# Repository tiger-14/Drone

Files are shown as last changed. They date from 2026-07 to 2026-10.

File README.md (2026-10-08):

# TSA Drone Project
A custom-built quadcopter drone with an integrated claw and live video feed, designed to remotely locate and retrieve caged and uncaged animals for TSA's 2026 Drone Challenge (Safari Rescue mission).





## 30+ Page Documentation Portfolio
The portfolio documents the complete build process of the drone with a photo log, a work log, engineered drawings, wired diagrams, and more

[Documentation Portfolio - Drone Challenge UAV.pdf](https://raw.githubusercontent.com/tiger-14/drone/main/Documentation%20Portfolio%20-%20Drone%20Challenge%20UAV.pdf)

## Features

- 3D-printed frame, base structure, and claw mechanism, designed in SolidWorks
- 4x brushless motors (RS2205 2300KV) with tri-blade propellers for lift and thrust
- SoloGood F722 flight controller stack running Betaflight firmware in Angle Mode for automatic self-leveling
- BetaFPV ELRS 2.4GHz receiver paired with a BetaFPV controller for piloting
- Raspberry Pi Zero WH running Raspberry Pi OS, controlling the claw servos and USB webcam independently of the flight stack
- 3x SG90 micro servos actuating a 3-pronged claw for picking up and releasing targets
- XT30/XT60 smoke stopper for short-circuit protection
- Dual 3S LiPo 11.1V 5000mAh batteries

## How it works

The pilot flies the drone using a BetaFPV controller, which sends inputs to the onboard ELRS receiver at up to 500Hz. Betaflight, running on the SoloGood F722 stack, reads these inputs alongside data from the onboard IMU (gyroscope + accelerometer) and calculates motor outputs at 4-8kHz to keep the drone stable. In Angle Mode, the drone self-levels whenever the sticks are centered, which keeps it steady during claw operations without needing constant manual correction.

A Raspberry Pi Zero WH, handles the claw and camera. It drives the 3 SG90 servos that open and close the claw, and streams a live feed from a USB webcam back to the pilot's laptop for target identification. Betaflight and the Pi operate independently: Betaflight handles flight, the Pi handles the mission payload.

## Bill of Materials

| Part | Description | Qty |
|---|---|---|
| Anycubic Kobra 2 | 3D printer | 1 |
| Sunlu PETG | Print filament | 4 |
| Drone Frame (3D-printed) | Upper + lower frame housing all components | 2 |
| XT30/XT60 FPV Smoke Stopper | Short-circuit protection | 1 |
| Raspberry Pi Zero WH | Claw + video control | 1 |
| OVONIC D15 Dual LiPo Charger | Battery charging | 1 |
| 3S LiPo 11.1V 5000mAh | Power | 2 |
| BetaFPV Controller | Piloting | 1 |
| BetaFPV ELRS (2.4GHz, 500Hz) | Radio link | 1 |
| SoloGood F722 Stack | Flight controller | 1 |
| Readytosky RS2205 2300KV Brushless Motor | Lift/thrust | 4 |
| 5.1" 3-Paddle Propellers | — | 12 |
| Webcam | Target ID / video feed | 1 |
| SG90 Micro Servos | Claw actuation | 3 |
| 5V Converter | Powers Pi + servos | 1 |
| Claw (3D-printed) | Pickup mechanism | 1 |

## Compliance

Built and flown in accordance with FAA Part 107 and Remote ID requirements, 400ft altitude ceiling, and Georgia state UAS regulations. Full regulatory breakdown in the documentation portfolio.

## Credits

Built by Benjamin Antony, Taran Vijayakumar, Nathaniel Ramnath, and Ivin George for South Forsyth High School's TSA chapter — Georgia TSA SLC 2026, Athens, GA.

3D model sources: claw arm, landing gear, propeller guard, Pi enclosure, servo/webcam mounts, and drone frame base are credited with links in the documentation portfolio's Resources section.

## License


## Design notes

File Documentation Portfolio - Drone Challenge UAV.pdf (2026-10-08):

## Drone Challenge (UAV) 2026 Safari Rescue - HS Drone UAV

Conference City and State:

Georgia TSA State Leadership Conference (SLC) 2026 Athens, Georgia

School/Chapter:

South Forsyth High School
Cumming, Georgia - 30041

Team Members:

Benjamin Anthony
Taran Vijayakumar
Nathaniel Ramnath
Ivin George

## Table of Contents

Section | Page
Photo Log | 3-12
Wiring Diagrams | 13
Programming Software Explanation | 14-16
Engineered Drawings | 17-19
Bill of Materials | 20-21
Drone Regulations | 22-23
Resources & Sources | 24
Worklog | 25-27
Student Copyright Checklist | 28-31

## Photo Log

Photo 1 - Designing the Drone Frame on SolidWorks

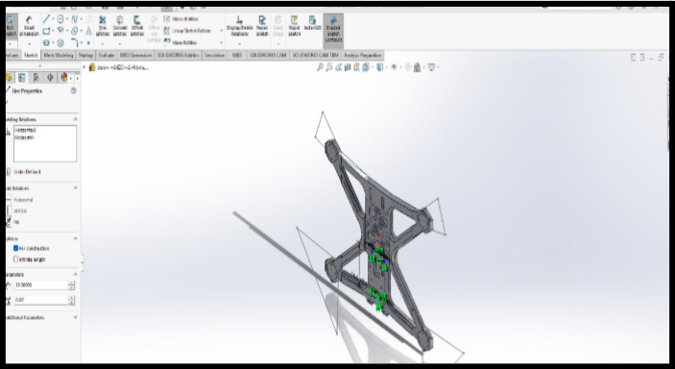
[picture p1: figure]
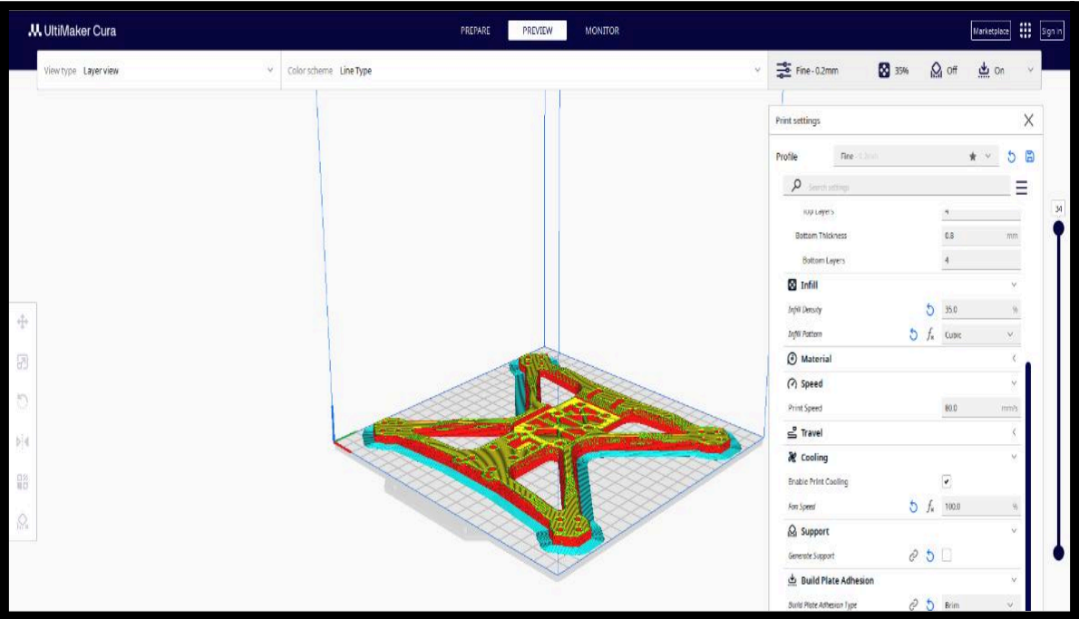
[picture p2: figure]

These images show the initial 3D modeling of the drone frame in SolidWorks. Designing the frame digitally allowed accurate planning before printing and ensured all components would fit properly.

Photo 2 - Attaching Motors to 3D-Printed Frame

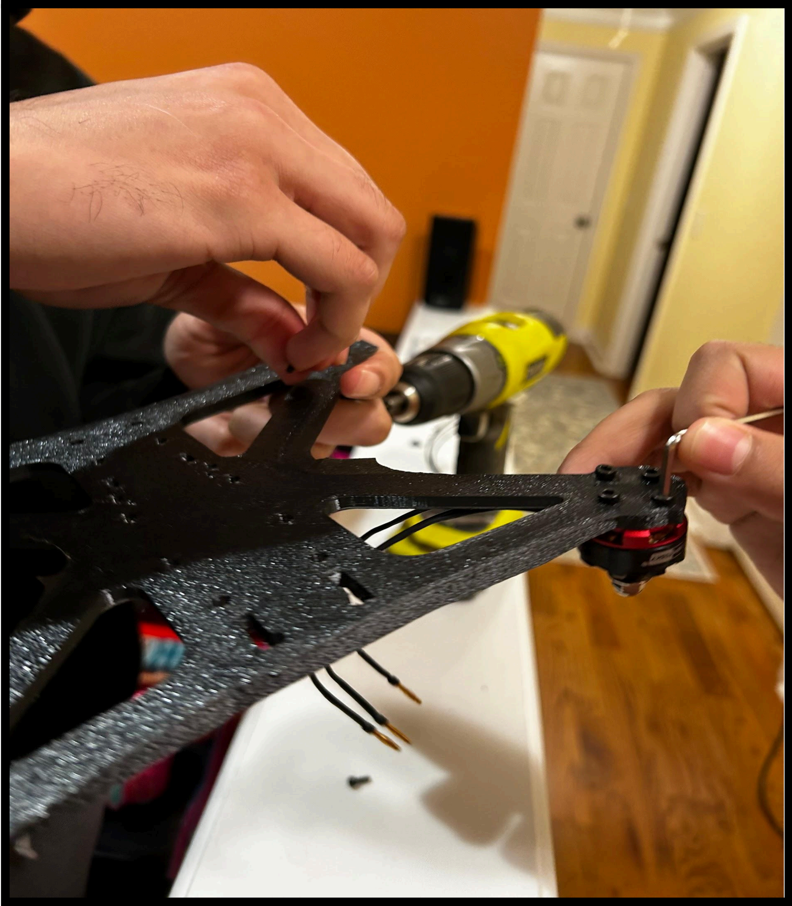
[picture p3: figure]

In this step, the motors were screwed onto the 3D-printed drone frame, ensuring each motor is securely mounted and ready for wiring.

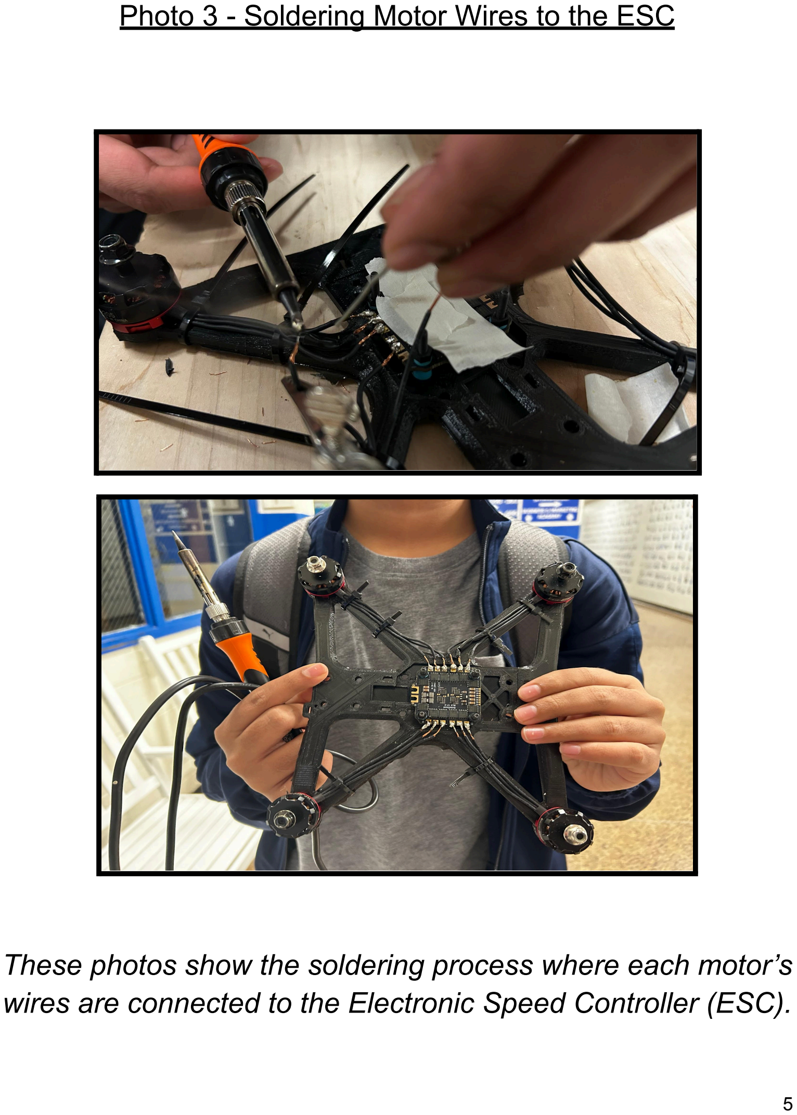
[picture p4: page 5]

Photo 3 - Soldering Motor Wires to the ESC

These photos show the soldering process where each motor’s wires are connected to the Electronic Speed Controller (ESC).

Photo 4 - Installing Flight Controller and ELRS

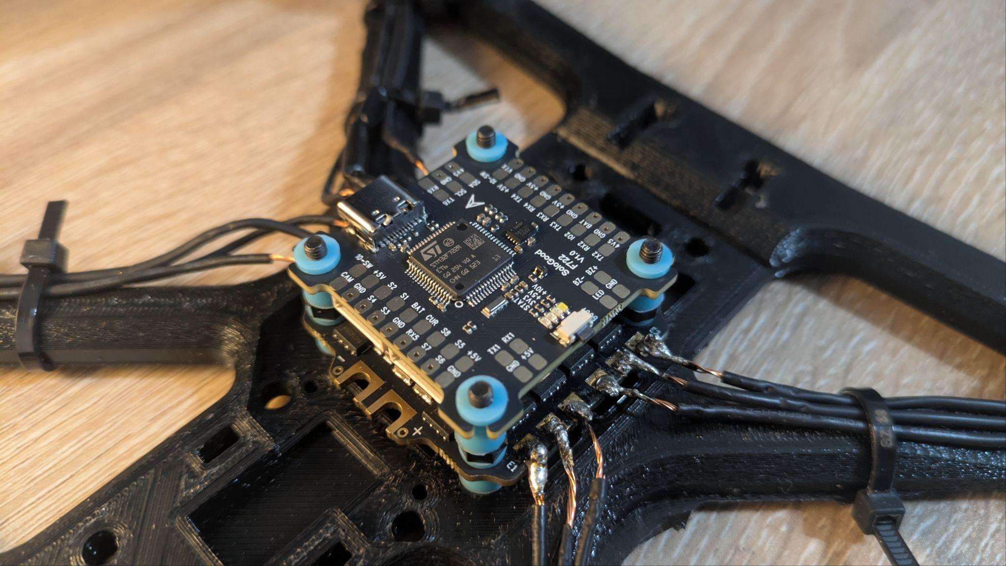
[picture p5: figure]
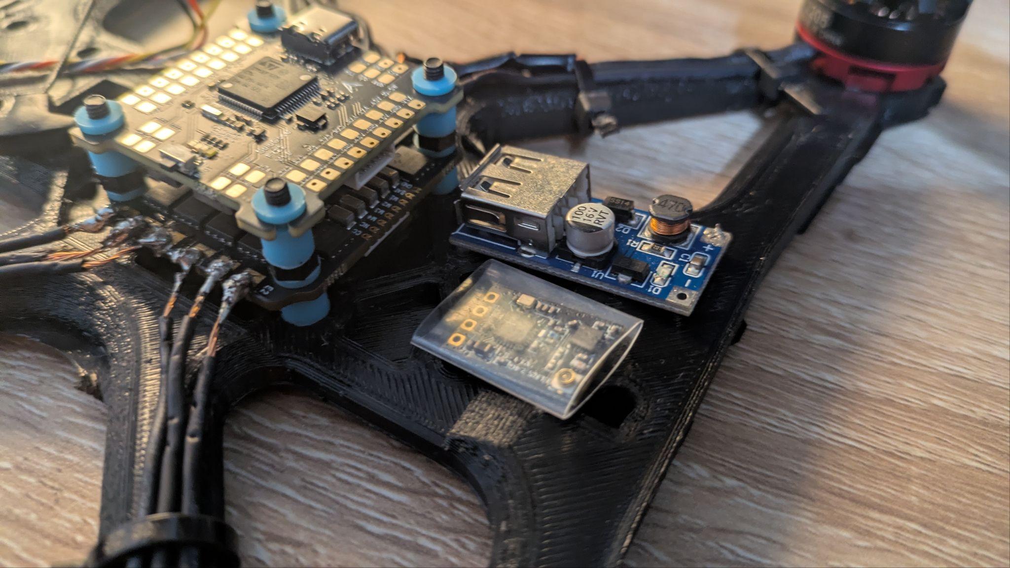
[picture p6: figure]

These photos show the installation of the flight controller and the ELRS receiver, completing the drone’s control and communication system.

Photo 5 - Installing Top Frame

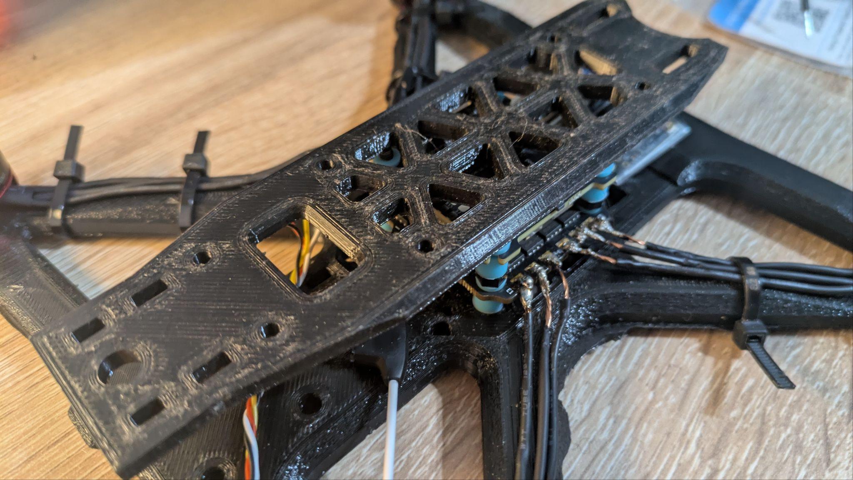
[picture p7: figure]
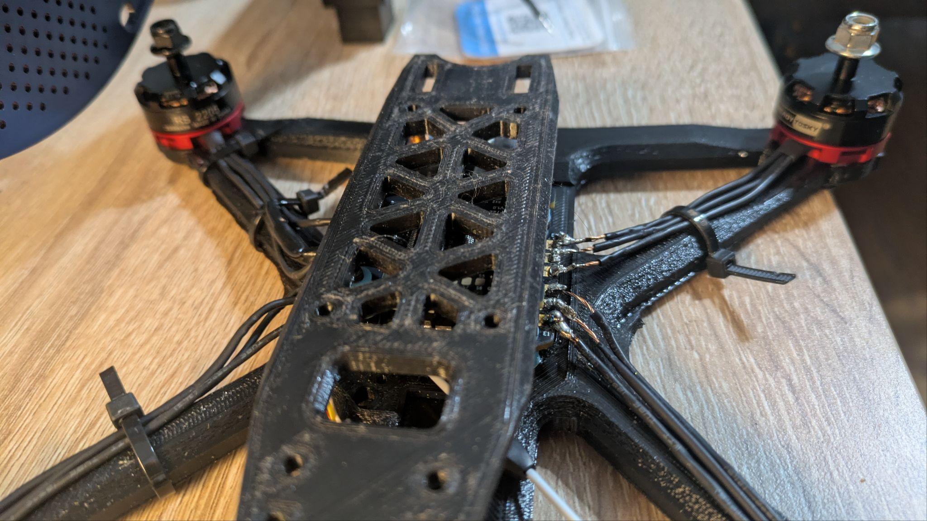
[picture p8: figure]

These photos show the installation of the 3D-printed top frame above the ESC, securing and protecting the components.

Photo 6 - Soldering battery wires to the ESC

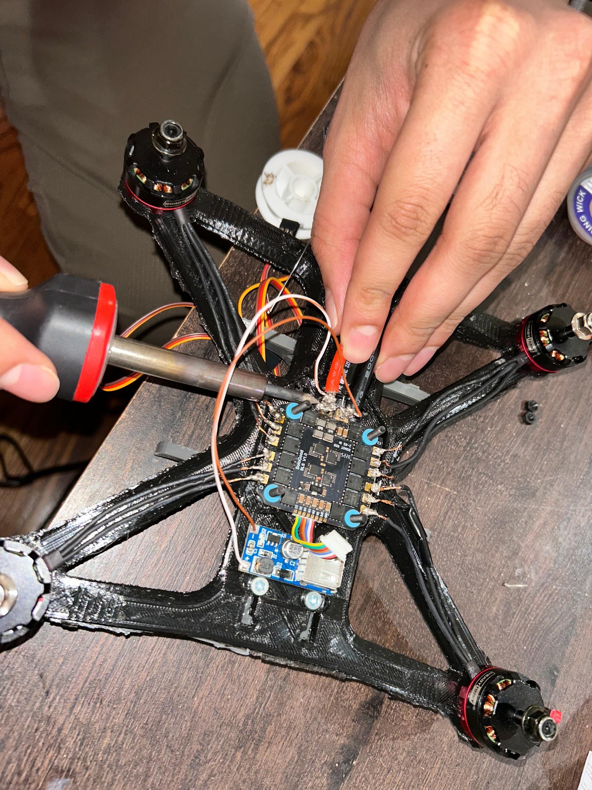
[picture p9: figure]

These photos show the soldering process where the drone’s battery power leads (positive red and negative black wires) are connected to the ESC power input pads, ensuring current delivery to all four motors.

Photo 7 - Connecting Ribbon Cable to the Flight Controller

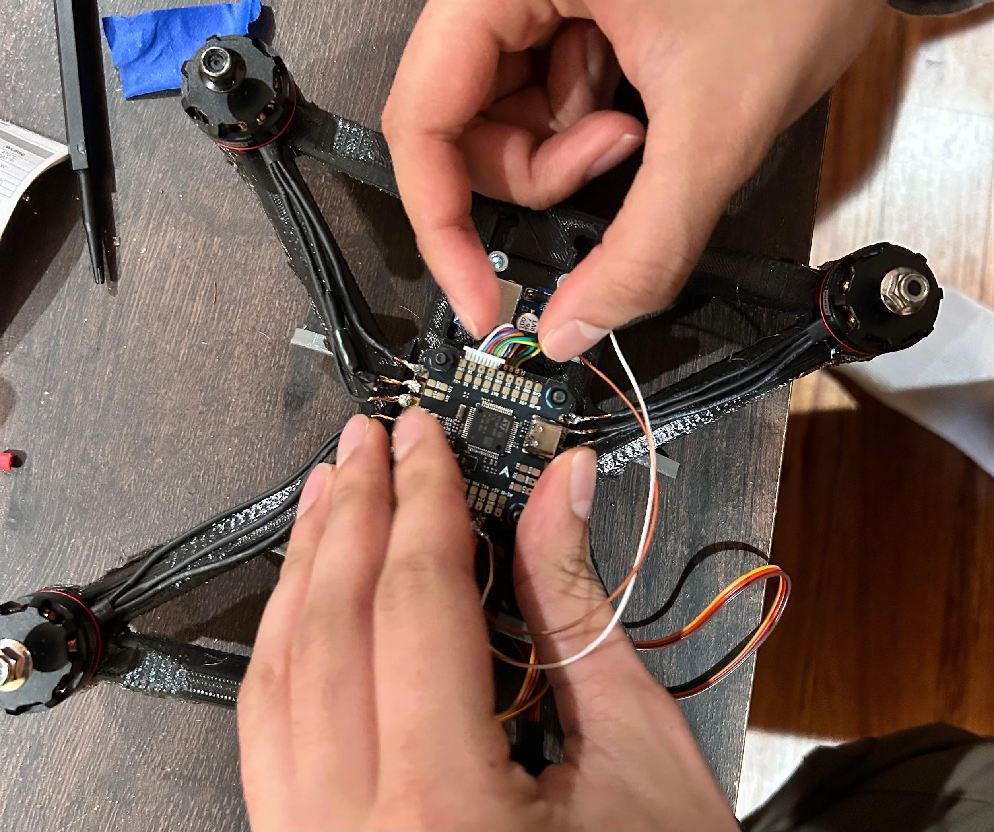
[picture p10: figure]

This photo shows the ribbon cable connection between the ESC and the flight controller for power and signal transmission.

Photo 8 - Connecting Ribbon Cable to the Flight Controller

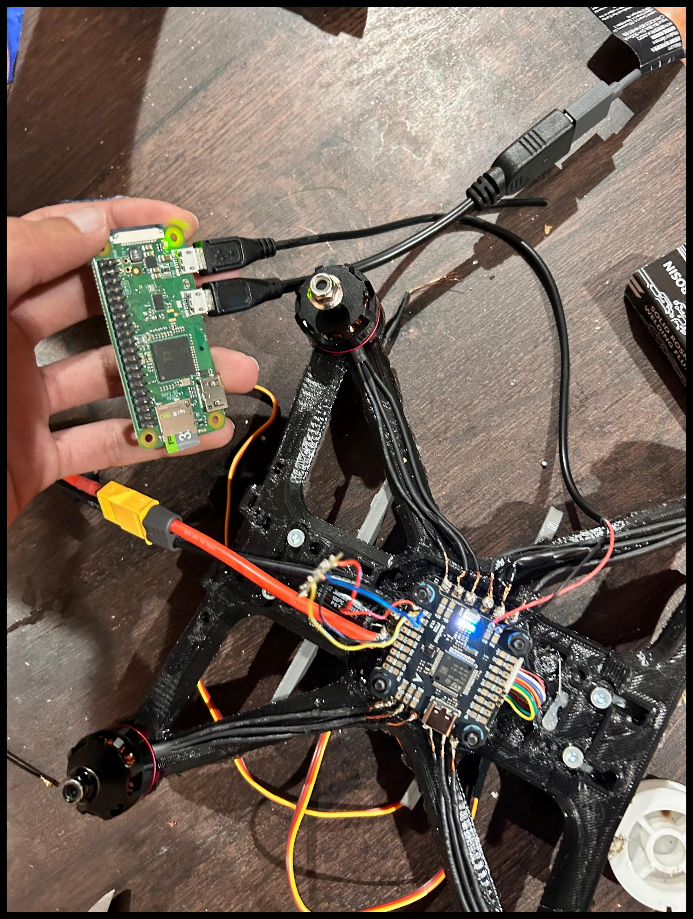
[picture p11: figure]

This photo shows the Raspberry Pi connected to the drone’s flight controller to control the claw and webcam.

Photo 9 - Raspberry Pi and Webcam Mounted

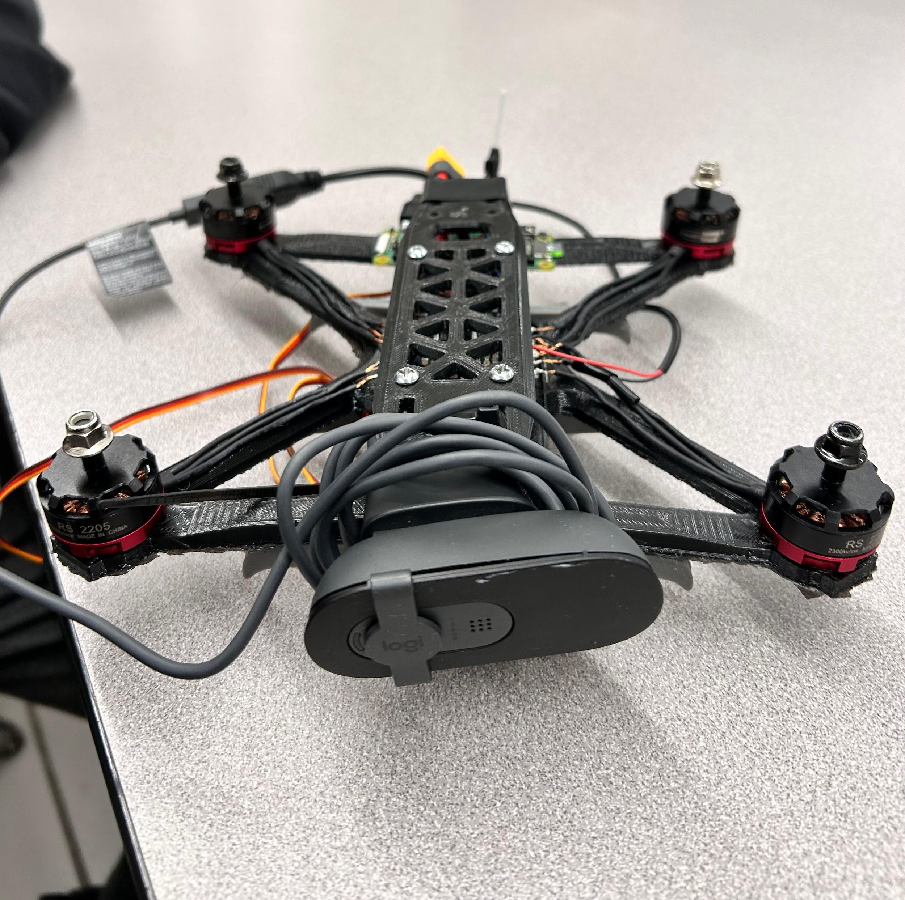
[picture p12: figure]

This photo shows the Raspberry Pi and webcam securely mounted on the drone frame.

Photo 10 - Drone connected to Betaflight configurator

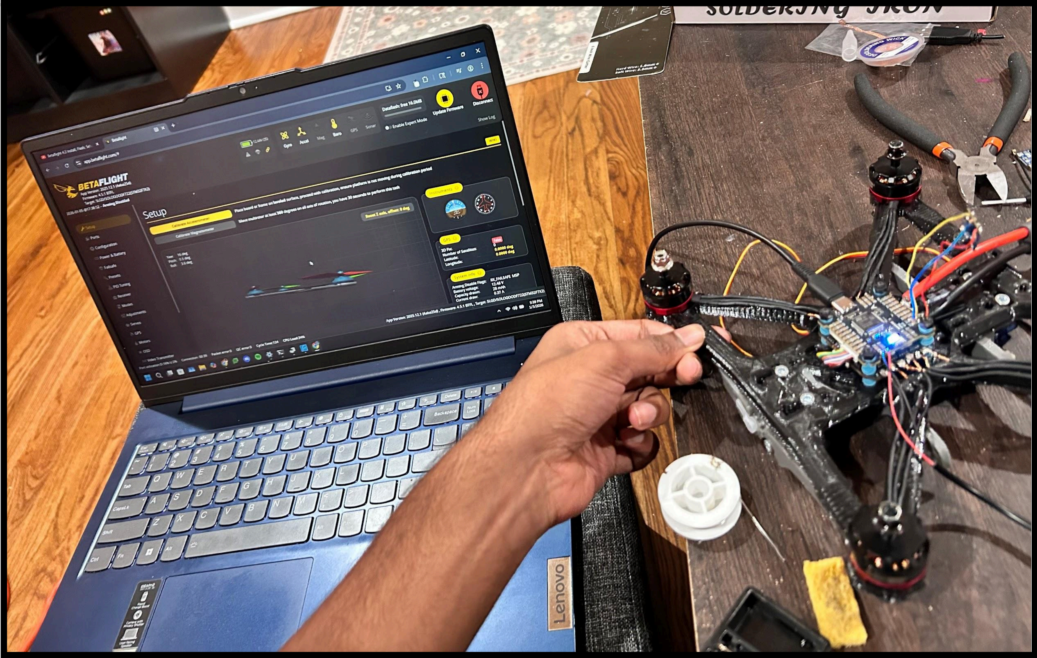
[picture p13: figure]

This photo shows the drone connected via USB to a laptop running Betaflight Configurator for flight control setup, receiver binding, controller and motor testing.

[Drone is currently under development. Photo log and other documentation will continue to be updated.]

## Wiring Diagram

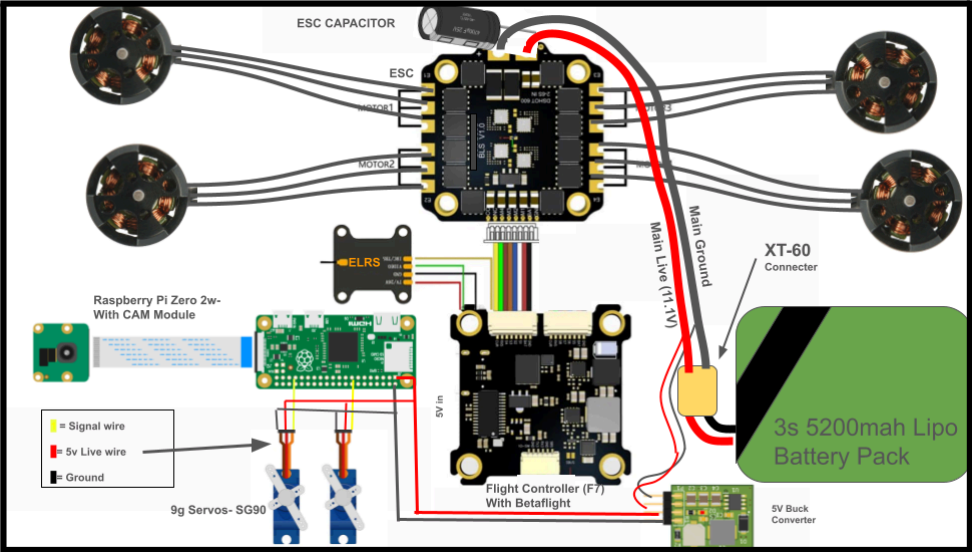
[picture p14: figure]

The information contained in this drawing is the sole property of Benjamin Antony, Taran Vijayakumar, Nathaniel Ramnath and Ivin George.

[Source of Flight Stack image: SoloGood FC Product Manual, used for illustrative purposes only]

## Programming Software

Betaflight is an open-source flight control firmware that runs on the drone’s flight controller microprocessor (in this build: STM32 F722 SoloGood stack) and acts as the central system coordinating all electronics. It continually processes pilot commands received via radio link (here using a BetaFPV ELRS 2.4 GHz receiver operating at 500Hz with the BetaFPV controller) while reading data from an Inertial Measurement Unit (IMU) containing a 3-axis gyroscope and 3-axis accelerometer.

For this Safari Rescue mission, we configured the drone to operate in Angle Mode, which provides automatic self-leveling for stability.Betaflight is good for our project because when the sticks are centered in Angle Mode, the outer loop commands zero tilt, causing the drone to actively self-level and maintain stable hover. This automatic stabilization is essential during our claw operations, as it eliminates the need for manual corrections and allows us to focus on collecting the target and claw positioning.

With Betaflight software, we will be able to tune our drone to our liking with many settings like PID, throttle response, and filters, which will allow the drone to fly optimally. The PID will be used for controlling how the vibrations from our brushless motors affect our drone in flight. This is extremely important to make sure our drone doesn't do anything that could cause harm to the components, which is exemplified by the fact that our frame is 3D printed.

Betaflight also allows us to configure the drone without manually making code for our specific motherboard, which will speed up the process of tuning and connecting the drone. Betaflight will also give us full control of everything connected to the motherboard, which includes servos, transmitter, and video broadcasting system.

Our flight control loop also operates at high speeds: the ICM42688P gyroscope can sample up to 8 kHz, with PID calculations typically running at 4-8 kHz depending on processor load and enabled features. This is combined with the ELRS (ExpressLRS) radio control protocol, which works with the controller’s pilot inputs sent to the ELRS receiver installed on the drone, with up to 500Hz update rate. Rapid input transmission from

ExpressLRS and high frequency sensor feedback from the gyroscope contribute to the drone’s extremely low latency.

We will be using Betaflight in conjunction with a Raspberry Pi Zero WH (which has its own power rail) to operate the claw system and transmit the video signal to our laptop. The Pi will be running Raspberry Pi OS, which is a custom version of Linux. This will connect to the signal wires for our servos and our USB webcam via the USB OTG port included in the microcomputer. The Betaflight software will also have control of our BetaFPV ELRS system, which connects the drone to the remote control system. This will allow us to tune our telemetry signal as well, and get the most performance out of our ELRS system for our specific use case.

Essentially, Betaflight is the flight control firmware that manages and allows all the major parts of the drone to work together.

## Engineered Drawings

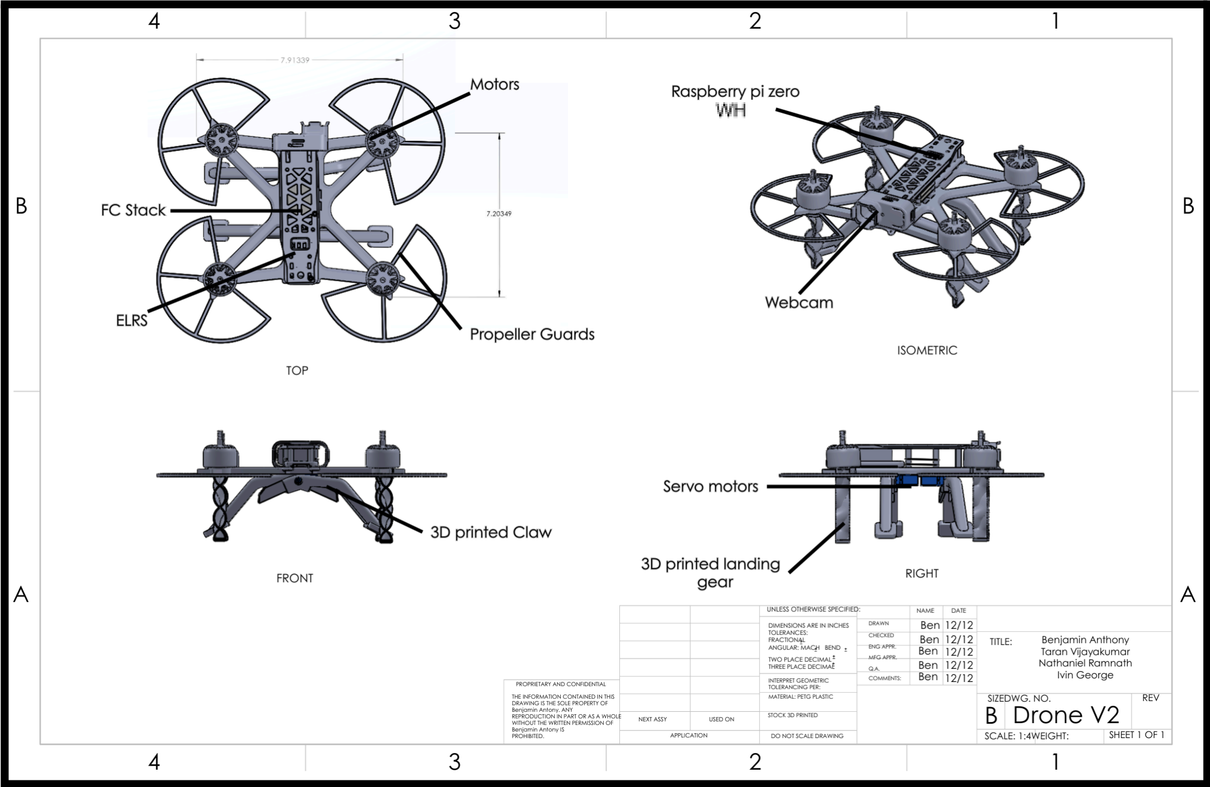
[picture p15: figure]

This engineered drawing shows the base frame, propeller and motor system, Raspberry Pi, claw, webcam, and all electronics. It shows the complete Safari Rescue drone configuration.

Base Frame

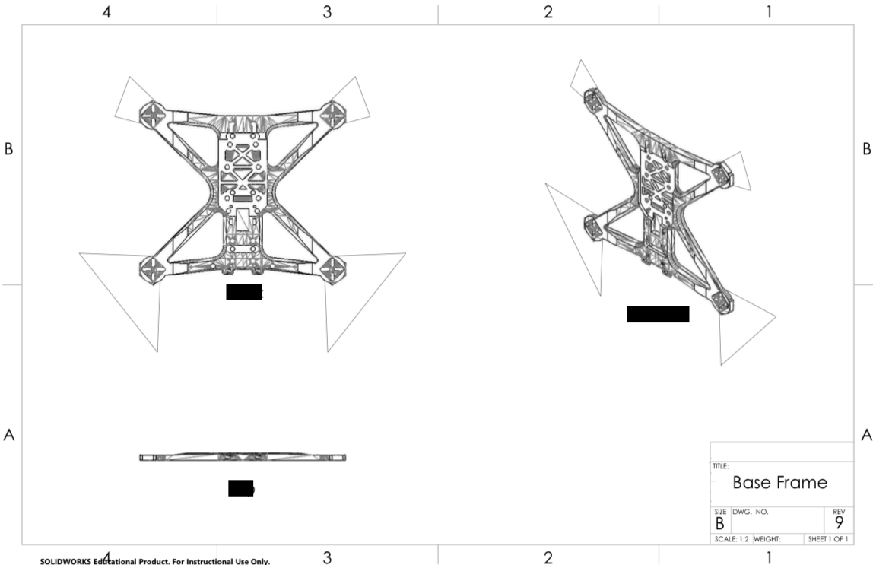
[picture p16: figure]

This engineered drawing shows the base frame with motor mounting holes and electronics mounting points. The design holds the motors, flight controller, ESC, and battery securely in place. It provides the main structure that connects all major components together for stable flight.

Gripper/Claw

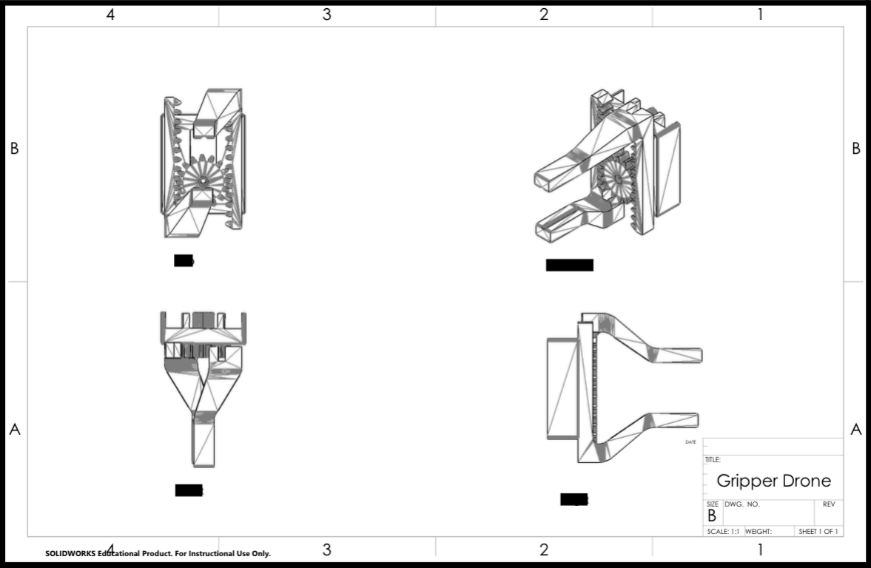
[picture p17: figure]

This engineered drawing shows the claw mechanism and grip design. It holds and releases the caged and uncaged animals for the safari rescue mission.

The information contained in these drawings are the sole property of Benjamin Antony, Taran Vijayakumar, Nathaniel Ramnath and Ivin George. Also reference the links in the Resources page.

## Bill of Materials

Parts | Description | Quantity
Anycubic Kobra 2 | 3D Printer | 1
Sunlu PETG | Filament for 3D printer | 4
Drone Frame | 3D-printed drone frame - It supports and protects all drone components, with the lower frame mounting the ESC and the upper frame supporting the flight controller, Raspberry Pi, and claw system. | 2
XT30/XT60 FPV Smoke Stopper (https://www.amazon.com/gp/aw/d/B0F8Q3GBMV/ref=ox_sc_act_image_1?smid=AX831X7Z04MWN&psc=1) | Short circuit protection - Protects stack and Raspberry Pi from catching on fire and protects | 1

electronic components from current surges.

Raspberry Pi Zero WH | For handling the video feed and servo motors | 1
OVONIC D15 Dual LiPo Battery Charger | Charges the battery | 1
3S LiPo 11.1V 5000mAh battery (https://www.amazon.com/gp/aw/d/B0D8SDTZ6P/ref=ox_sc_act_title_6?smid=A1KODDOPEPALCP&psc=1) | Powers the drone and associated systems | 2
Beta FPV controller (https://www.amazon.com/gp/aw/d/B09PV8C3D3/ref=ox_sc_act_title_3?smid=AHYBUG4B9GJPC&psc=1) | For controlling and piloting the drone | 1
Beta FPV ELRS (0.7 g, 2.4 GHz, 5 V, 500Hz) (https://www.amazon.com/gp/aw/d/B09B28HSVB/ref=ox_sc_act_title_4?smid=AHYBUG4B9GJPC&psc=1) | Sends signal from the drone to the controller | 1
SoloGood F722 Stack (https://www.amazon.com/gp/aw/d/B0CQJVGK14/ref=ox_sc_act_title_5?smid=A1JGQIWP459RKC&psc=1) | It acts like the motherboard of the drone, it determines motor speed and interprets signals | 1

Readytosky
RS2205 2300KV
Brushless Motor
CW/CCW 3-4S
RC Motors
| Brushless motor that spins propellers to generate lift and provide thrust for flight. | 4
| Creates lift to fly the drone | 12
Webcam | Provides a camera feed and target identification | 1
SG90 Micro Servos (from open-lab) | Powers the claw to pick up objects | 3
5V Converter (from open-lab) | 5V regulator to power Raspberry Pi and servos. | 1
Hand drill | Used for creating mounting holes to attach motors and other components to drone frame | 1
Claw | 3D printed and used to pick up objects | 1

5.1inch, 3-Paddle
Propellers (https://www.amazon.com/gp/aw/d/B0F632WFJQ/ref=ox_sc_act_title_7?smid=AX831X7Z04MWN&psc=1)

## Rules & Regulations

Federal Rules and Regulations:

In accordance with the Federal Aviation Administration (FAA) regulations, any unmanned aircraft weighing more than 250 grams must be registered with the FAA and must comply with RFID (Remote ID) requirements unless operated within a FAA-Recognized Identification Area (FRIA). Pilots must ensure that the aircraft’s Remote ID broadcast is functional prior to takeoff, as it transmits the drone’s location and registration information for accountability and airspace safety.

The maximum allowable altitude for all drones is 400 feet above ground level. The aircraft must be maintained within Visual Line of Sight of the pilot or a dedicated spotter at all times. FPV (First Person View) operations are allowed only when a visual observer maintains unaided visual contact with the drone. Prior to flight, pilots are required to check the FAA B4UFLY application for airspace restrictions, such as those found near airports, military bases, or other controlled airspace. Drone flight is prohibited over national parks, and large gatherings of people, unless specific authorization is granted.

Operations near critical infrastructure such as power plants, hospitals, and transmission lines are discouraged unless explicitly approved. All pilots are required to complete the FAA TRUST exam and have the required certification. The drone must not interfere with emergency response, law enforcement, or firefighting activities.The drone may not drop or release objects in a manner that creates a hazard to people or property. Flights should be conducted during daylight or civil twilight hours in accordance with FAA safety guidelines.

Local/Regional Rules and Regulations:

All operations comply with applicable Georgia state laws regarding unmanned aircraft systems and privacy. Operators are restricted from recording or photographing in areas where individuals have a reasonable expectation of privacy. Flight over state parks, public gatherings, correctional facilities, and using a drone to nuisance or annoy someone is strictly prohibited. Flights over private property without the property owner’s consent are prohibited. Obtaining prior permission from local authorities or park services is required for any educational or research-based drone missions in these areas. Giving way to manned aircraft is also required as well as requiring authorization to fly near the local Athens-Ben Epps Airport (AHN). Operators should file a LAANC (Low Altitude Authorization and Notification Capability) request when flying within controlled airspace near airports to ensure compliance with FAA airspace management.

## Resources & Sources

3D models used:

Claw arm:
https://www.printables.com/model/1460464-replacement-arm-claw-for-pik-stik-grabber-tool/files

Landing Gear:
https://www.printables.com/model/67370-drone-landing-gear-sjrc-f11-pro

FPV drone propeller guard: https://www.printables.com/model/1302713-5-fpv-drone-propeller-guard

Raspberry Pi Flight Case:
https://www.printables.com/model/703964-raspberry-pi-zero-2w-enclosure

Servo Mockup:
https://makerworld.com/en/models/1140652-sg90-micro-servo-9g-with-step#profileId-1142959

Webcam Mockup:
https://makerworld.com/en/models/1748017-runcam-thumb-2-fpv-camera-mount#profileId-1858095

Drone Frame Files (ours is modified):
https://makerworld.com/en/models/1336260-5-inch-fpv-drone

Case for 5V Buck Converter: https://www.printables.com/model/326052-buck-converter-case

Mockup of ESC and FC Board: https://www.printables.com/model/860808-mark4-drone-frame-stack-isolator

Mockup For FPV drone motors: https://www.printables.com/model/665249-iflight-xing-2814-bldc-drone-motor

Videos used:

BetaFPV binding: https://youtu.be/3rdvve-Ecuc?si=N1mL7NIPLary5r7v

Soldering tutorial: https://www.youtube.com/watch?v=l5hiIbGMowk

## Work Log

Date | Time spent | Team Members Present | Task/Activity | Materials Used | Progress | Next Steps
10/7/2025 | 1.5 hrs | Ben, Taran | Brainstormed potential designs for drone challenge | Laptops, Internet research | Figured out a clear roadmap and that we needed motors that can hold 1 kilogram of weight each | Find out parts online for budget of $300 and more research for drone
10/21/2025 -10/22/2025 | 3 hrs | Ben, Taran | Conducted research on drone designs | Laptops, and Research notes | Compiled data on materials and links to purchase design | Finalize list and then order parts in advance
10/25/2025 -10/26/2025 | 5 hrs | Ben, Taran | Finalize compiled list of materials | Laptops and Research notes | Ordered list of needed materials for drone design | Start concept sketches and rough models.
10/27/2025 -10/28/2025 | 4 hrs | Ben, Taran, Nathaniel, Ivin | Created concept sketches. | Solidworks 2024 | Agreed on 3D design on Solidworks and finished drone sketch, and parts report | Begin Plan for drone and finalize checkpoint 0 submission
11/30/2025 | 4.5 hrs | Ben, Taran, Nathaniel, Ivin | Mounted motors to 3D-printed drone frame | Drill, Screws, Motors, and Drone frame | Mounted all 4 motors and began soldering | Solder motor wires to the ESC

12/1/2025 -12/2/2025 | 3 hrs | Ben, Taran, Nathaniel, Ivin | Solder motor wires to the ESC and work on portfolio | Soldering iron, Solder, Wire strippers, and Helping hands with clamps | Finished soldering motor wires and worked on portfolio | Finish documentation portfolio
12/7/2025 | 2.5 hrs | Taran | Work on portfolio | Laptop, Research Notes, and Pictures | Finished first page,index, photo log, work log and worked on bill of materials | Finish documentation portfolio -engineered drawings and wired diagrams
12/8/2025 | 2 hr | Ben, Nathaniel, Taran | Find parts in open-lab and work on portfolio | Laptop, Scissors, and Battery to test converter, and open-lab | Found a 5V converter and wires for our drone and figured out how to wire the ELRS | Finish documentation portfolio -engineered drawings and wiring diagrams
12/10/2025 | 2.5 hrs | Ben, Taran | Work on engineered drawings | Laptop, Solidworks | Finished 3D-modeling of drone for the engineered drawings | Finish documentation portfolio -engineered drawings and wiring diagrams
12/12/2025 | 5.5 hrs | Ben, Taran, Ivin | Work on finishing the whole documentation portfolio | Laptop, Solidworks, Research Notes, and Pictures | Finished Documentation Portfolio and submitted for checkpoint 1 | Finish building the drone and dropping mechanism.
1/4/2026 | 5 hrs | Ben, Taran, Nathaniel, Ivin | Work on setting up the drone for flight | Laptop, Soldering iron, Solder, Raspberry Pi Zero WH, SD card reader | Finished imaging and flashing the Raspberry Pi and soldered the battery. | Attach a webcam powered by the Raspberry PI to the drone and power motors.
1/5/2026 | 5 hrs | Ben, Taran, Nathaniel, Ivin | Finish mounting of parts onto the drone and start flying it | Laptop, Soldering iron, Solder, Raspberry Pi Zero WH, SD | Mounted the Battery, Webcam and Raspberry Pi Zero WH to | Bind the ELRS and the controller successfully

| | | | card reader, BetaFPV Controller, and BetaFPV Configurator | the Drone frame | and begin flying the drone
1/6/2026 | 4 hr | Ben, Taran, Nathaniel, Ivin | Fix 3D printer and BetaFPV issues, add changes to documentation portfolio based on feedback, and begin flying the drone | Laptop, BetaFPV Controller, and BetaFPV Configurator | Added information to the drone flight regulations and work log sections of the documentation portfolio | Work on claw and fix BetaFPV issues
1/7/2026 | 3 hr | Ben, Taran, Nathaniel, Ivin | Fix 3D printer and motor issues | Laptop, BetaFPV Controller, and BetaFPV Configurator | Fixed 3D printer | Fix motor issues
1/9/2026 | 4 hr | Ben, Taran | Figure out how to make drone fly and finish changes to documentation portfolio | Laptop, BetaFPV Controller, and BetaFPV Configurator | Submitted updated documentation portfolio | Fix motor issues
1/11/2026 | 10 hr | Taran, Nathaniel, Ben, Ivin | Worked on claw and webcam, built the drone completely | Laptop, Soldering iron, Solder, Raspberry Pi Zero WH, SD card reader, BetaFPV Controller, and BetaFPV Configurator | Full drone completely assembled | Fix motor issues and raspberry pi
1/12/2026 | 7 hr | Taran, Nathaniel, Ben, Ivin | In house conference + resoldering | Drone | Identified motor issues and resoldered everything | Fix claw

## Student Copyright Checklist

STUDENT: Answer question 1 below.

1) Does your solution to the competitive event integrate any type of music and/or sound?

☐ YES ☑ NO

- If NO, go to question 2.
- If YES, is the music and/or sound copyrighted?

☐ YES ☐ NO

- If YES, move to question 1A.
- If NO, move to question 1B.

1A) Have you asked for author permission to use the music and/or sound in your solution and included that permission (letter/form) in your documentation?

☐ YES ☐ NO

- If YES, move to question 2.
- If NO, ask for permission and, if permission is granted, include the permission in your documentation.

1B) Is the music/sound royalty-free, or did you create the music/sound yourself?

☐ YES

- If YES, cite the royalty-free music/sound or your original music/sound properly in your documentation.

CHAPTER ADVISOR: Sign below regarding your student’s answer(s) to the use of music/sound in his/her competitive event solution. Even if your student answers “NO” to question 1, please sign below noting that you have evaluated the competitive event solution and the student answered the question(s) accurately.

I, ______________________________ (chapter advisor), have checked my student’s solution and confirm that any use of music/sound is done with proper permission and is cited correctly in the student’s documentation and/or the solution has been found to have no music/sound included.

STUDENT: Answer question 2 below.

2) Does your solution to the competitive event integrate any graphics and/or videos?

☑ YES ☐ NO

- If NO, go to question 3.
- If YES, is/are the graphics/videos copyrighted, registered, and/or trademarked?

☐ YES ☑ NO

- If YES, move to question 2A.
- If NO, move to question 2B.

2A) Have you asked for author permission to use the graphics and/or videos in your solution and included a permission (letter/form) in your documentation for each graphic/video used?

☐ YES ☐ NO

- If YES, move to question 3.
- If NO, ask for permission and, if permission is granted, include the permission in your documentation.

2B) Is/are the graphics/videos royalty-free, or did you create your own graphics/videos?

☑ YES

- If YES, cite the royalty-free graphics/videos or your original graphics/videos properly in your documentation.

CHAPTER ADVISOR: Sign below regarding your student’s answer(s) to the use of graphics/videos in his/her competitive event solution. Even if your student answers “NO” to question 2, please sign below noting that you have evaluated the competitive event solution and the student answered the question(s) accurately.

I, ______________________________ (chapter advisor), have checked my student’s solution and confirm that any use of graphics/videos is done with proper permission and is cited correctly in the student’s documentation and/or the solution has been found to have no graphics/videos included.

STUDENT: Answer question 3 below.

3) Does your solution to the competitive event use another’s thoughts or research?

☑ YES ☐ NO

- If NO, this is the end of the checklist.
- If YES, have you properly cited others’ thoughts or research in your documentation?

☑ YES ☐ NO

CHAPTER ADVISOR: Sign below regarding your student’s answer(s) to having integrated any thoughts/research of others in his/her competitive event solution. Even if your student answers “NO” to question 3, please sign below noting that you have evaluated the competitive event solution and the student answered the question(s) accurately.

I, ______________________________ (chapter advisor), have checked my student’s solution and confirm that any use of the thoughts/research of others is done with proper permission and is cited correctly in the student’s documentation and/or the solution has been found to have all original thought with no use of others’ thoughts/research.

Student Initials: TV / BA / NR / IG

Chapter Advisor Signature: ______________________________________________________

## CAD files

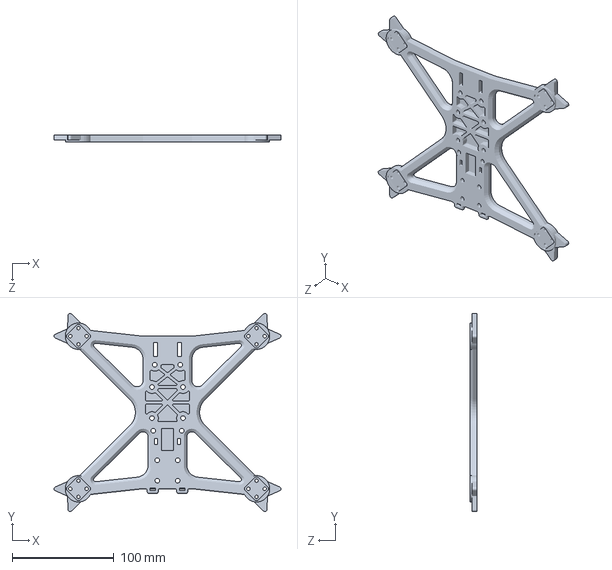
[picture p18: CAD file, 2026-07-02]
CAD files/Drone Frame Base.SLDPRT
223.1 x 194.9 x 7.00 mm

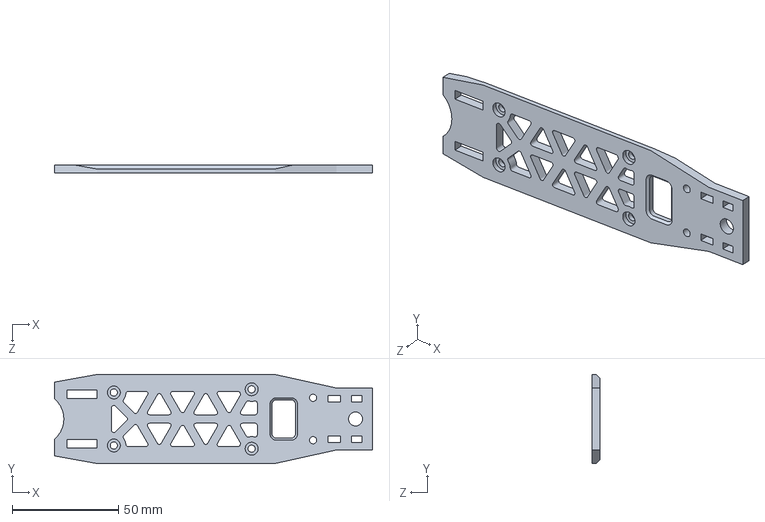
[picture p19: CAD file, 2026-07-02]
CAD files/Top Drone Frame.SLDPRT
150.0 x 42.0 x 4.00 mm

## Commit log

2026-07-02 Create CAD Models
2026-07-02 Create build timeline for drone project
    Added detailed build timeline for the drone project, including sections on team members, photo logs, wiring diagrams, programming software explanation, engineered drawings, bill of materials, rules a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
2026-07-02 Update README with project details and documentation
    Added detailed project information including team members, photo logs, programming software explanation, engineered drawings, bill of materials, rules and regulations, resources, and work log for the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
2026-07-02 Create Schematics and Diagrams
2026-07-02 Enhance README with project details and features
    Added detailed project description, features, compliance information, and a bill of materials for the TSA Drone Project. Included sections on operation, documentation, and team credits.
2026-07-02 Added all CAD Files
    these are solid works 2024 files
    [25mmframe V2.SLDPRT, Buck_converter_case_final V2.SLDPRT, Drone Propeller Guard V2.SLDPRT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]
2026-07-02 Organized all CAD files into one folder
    [25mmframe V2.SLDPRT, Buck_converter_case_final V2.SLDPRT, Drone Propeller Guard V2.SLDPRT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]
2026-07-02 Deleted extra files
    [25mmframe V2.SLDPRT, Buck_converter_case_final V2.SLDPRT, Drone Frame Base.SLDPRT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]
2026-11-10 Create Forge BOM
2026-11-11 Revise README for Claw Drone Project
    Updated project name and description, revised technical details, and improved compliance and credits sections.
2026-11-11 Revise project description in README.md
    Updated project description to reflect current status and goals.
2026-11-11 Update Forge BOM
2026-11-11 Revise BOM with additional parts and pricing
    Updated the BOM to include new parts with links and prices.
